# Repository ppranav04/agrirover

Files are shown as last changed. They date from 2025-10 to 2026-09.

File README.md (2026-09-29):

# Agrirover: Tomato Detection and 3D Localization on a Mobile Manipulator

Semester 7 Project-I, B.Tech Mechatronics and Automation, VIT Chennai (report title: *Agribot*)

Agrirover is a mobile manipulator platform for tomato harvesting. It combines a custom-trained YOLOv8
detector running on a Jetson Orin Nano, 3D localization from RealSense D435 depth, a 5-DOF arm driven
through ROS 2 and an Arduino Uno, and a compliant TPU end-effector.

<p align="center">
  
  
</p>

## Demo

Live tomato detection and 3D localization on the Jetson Orin Nano, followed by the end-effector picking
motion.

https://github.com/user-attachments/assets/91c9d1a5-2fdd-4766-8c50-547cba2d2344

## Results

| Metric | Value |
|---|---|
| Detection precision / recall (ripe) | 0.90 / 0.93 |
| Detection precision / recall (unripe) | 0.94 / 0.91 |
| F1 (ripe / unripe) | 0.91 / 0.92 |
| Test set | 784 annotated samples, overall accuracy 0.92 |
| 3D localization error, 0.15–0.50 m | RMSE 2.03 cm, MAE 0.98 cm |
| Goal-pose frame-to-frame jitter | < 1 mm (X, Y), 0.23 mm (Z) [static target: confirm] |
| Inference time, 480x640 | [5.5–9.3 ms, TensorRT: confirm] |
| Pipeline rate | 28 FPS |

Depth error was measured against [ground-truth method: e.g. tape measure at N distances].

## Perception

A ROS 2 node (`agrirover_perception`) that:

- runs a custom-trained YOLOv8n model on RealSense D435 color frames on a Jetson Orin Nano
  (Ubuntu 22.04, JetPack 6.2, ROS 2 Humble)
- classifies tomatoes as ripe or unripe
- reads depth at each detection's bounding-box center and deprojects it to a 3D point with the camera
  intrinsics
- transforms points from the camera frame to the robot base frame with a calibrated 4x4 transform
- publishes goal poses (`tomato/goal_pose`), RViz markers, a detection-status signal and an annotated
  image stream

## Manipulation

- 5-DOF arm with 3D-printed linkages, MG996R servos and a 500 mm reach
- Software chain: camera node, then IK node, then serial node, then Arduino Uno PWM servo control
- Compliant three-claw TPU end-effector; a worm-gear redesign that moves all three claws synchronously was
  designed in SolidWorks

## Robot description

URDF for the arm, camera mount and mobile base, with bringup launch files in `agrirover_bringup`.

## Roadmap

- MoveIt 2 motion planning between perception output and arm control
- Perception-driven pick-and-place
- Multi-frame tracking
- V-SLAM / LiDAR SLAM field navigation

## Repository structure

```
agrirover/                    Core package
agrirover_bringup/            Launch files, system startup
agrirover_description/        URDF and robot description
agrirover_manipulation/       IK node, serial node, end-effector logic
agrirover_perception/         Detection and 3D localization node
yolov8n_tomato.pt             Trained detection model
Datasets and Misc.zip         Training data and supporting files
```

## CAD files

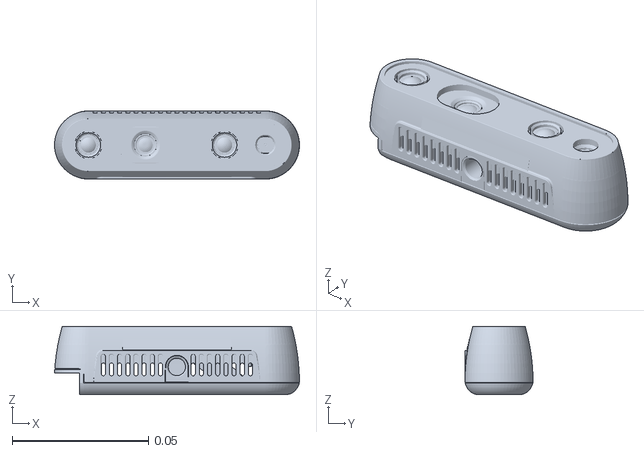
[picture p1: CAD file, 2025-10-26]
agrirover_description/meshes/d435/visual/d435.stl
0.0899 x 0.025 x 0.0251

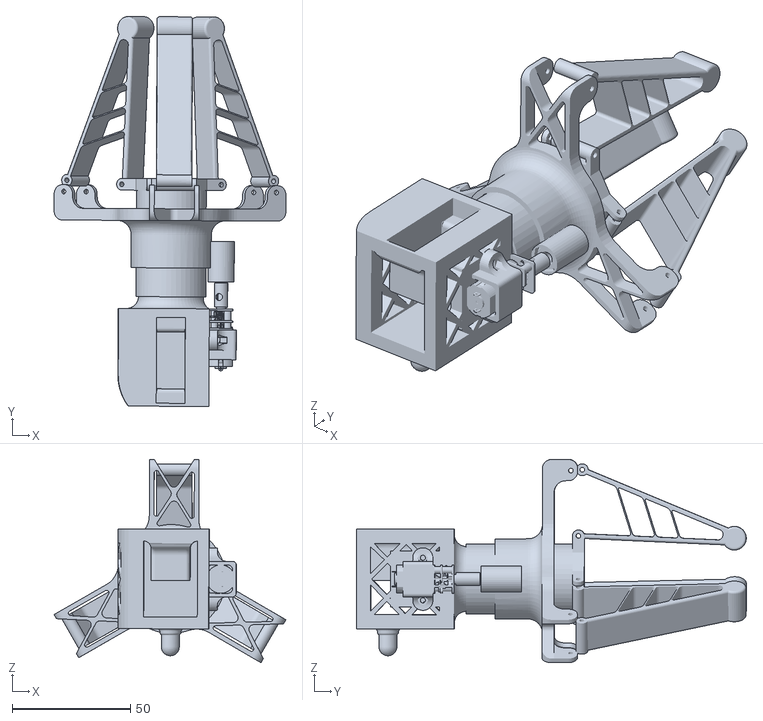
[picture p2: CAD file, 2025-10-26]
agrirover_description/meshes/end_effector.stl
98.1 x 165.0 x 86.0

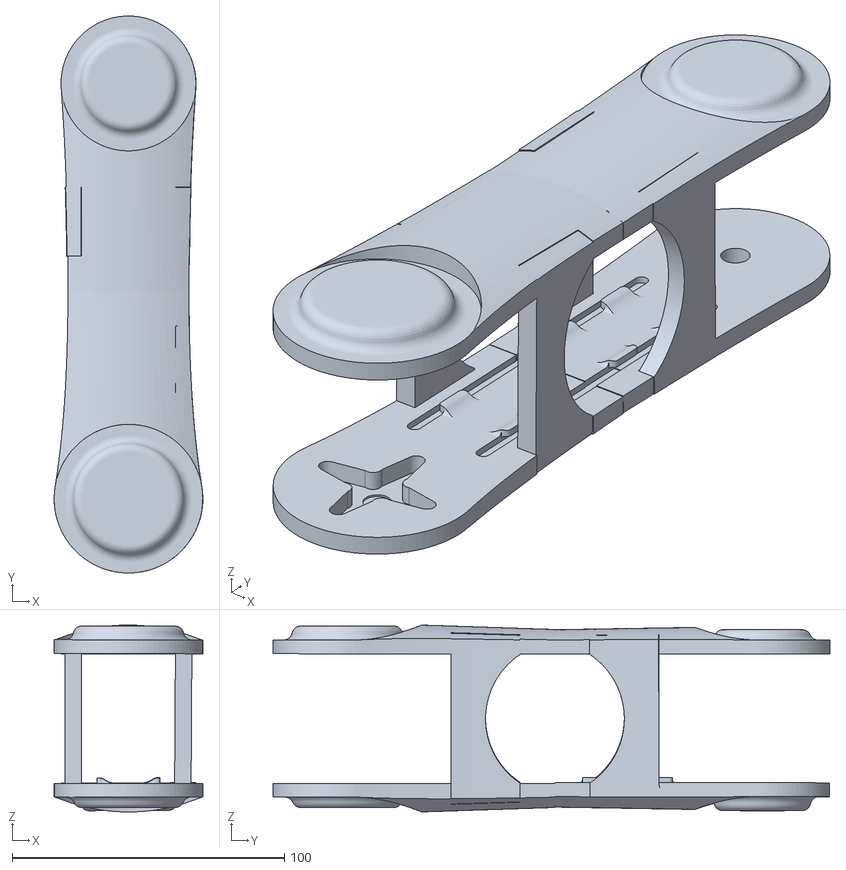
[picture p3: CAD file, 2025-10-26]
agrirover_description/meshes/Link_2.stl
54.7 x 204.6 x 68.7

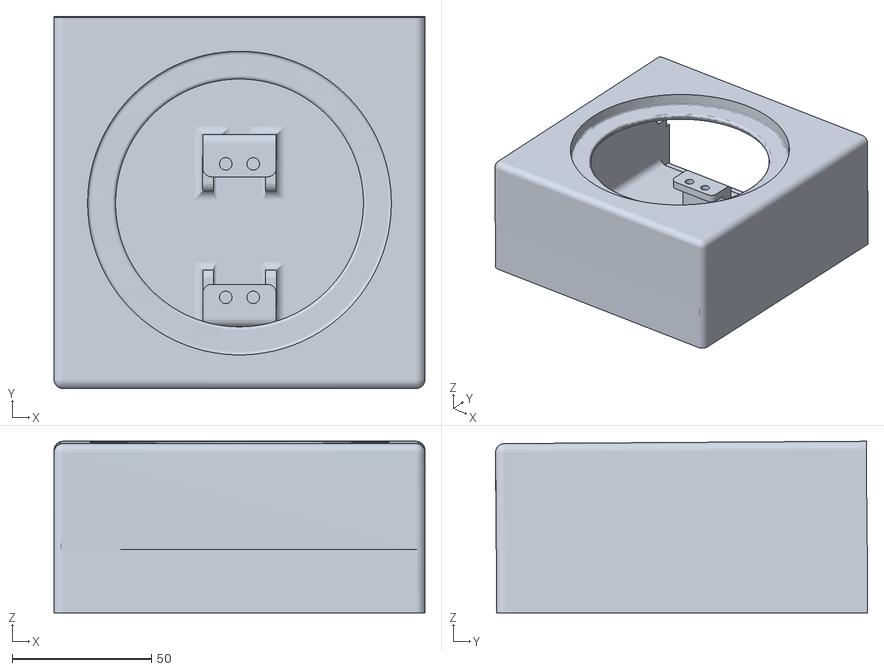
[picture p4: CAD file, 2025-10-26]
agrirover_description/meshes/Base_simplified.stl
133.4 x 133.7 x 61.7

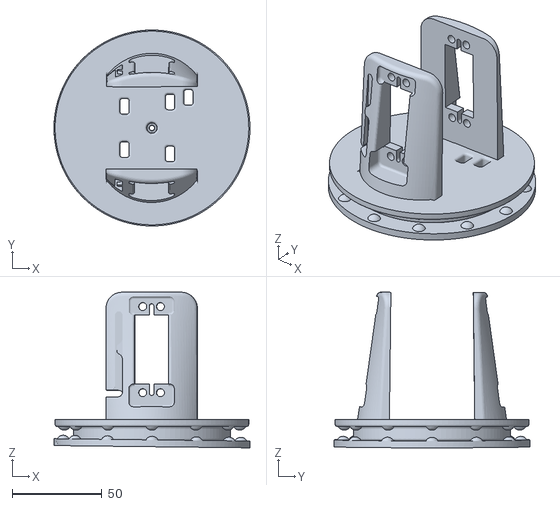
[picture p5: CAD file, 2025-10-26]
agrirover_description/meshes/Link_0_simplified.stl
109.2 x 109.2 x 86.8

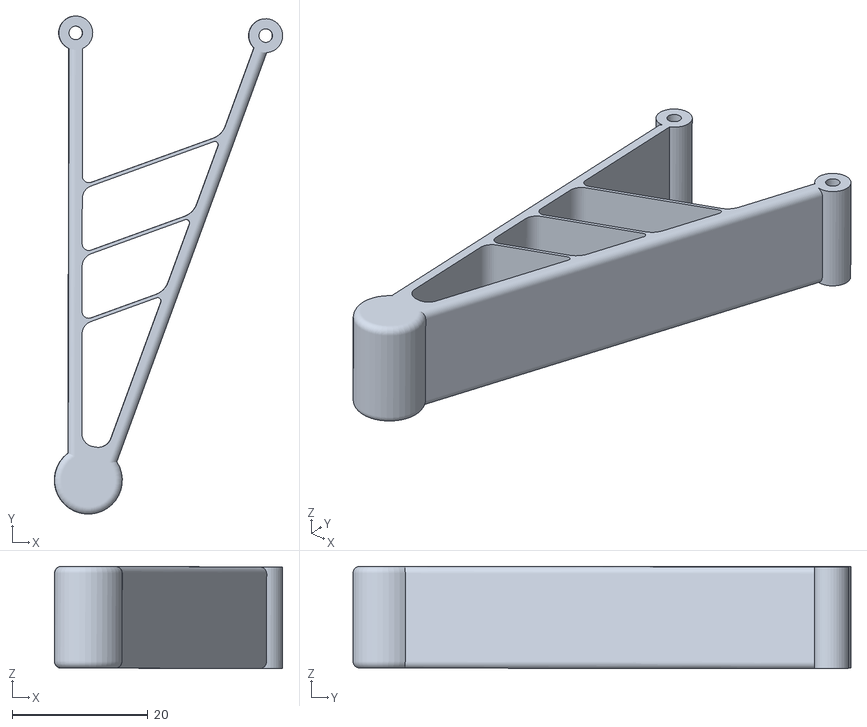
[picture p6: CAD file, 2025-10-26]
agrirover_description/meshes/finger.stl
33.7 x 73.5 x 15.1

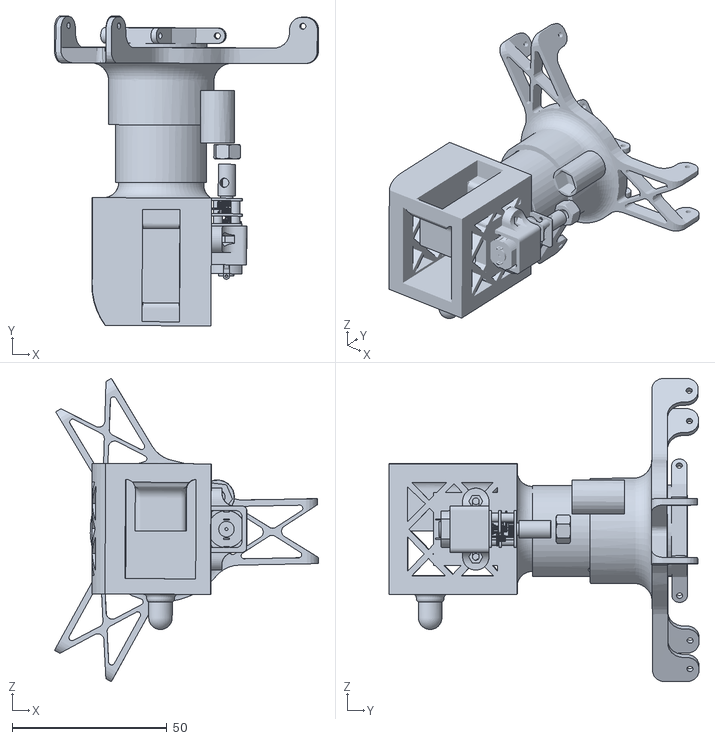
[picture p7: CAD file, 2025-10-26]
agrirover_description/meshes/gripper_simplified.stl
85.4 x 100.2 x 98.1

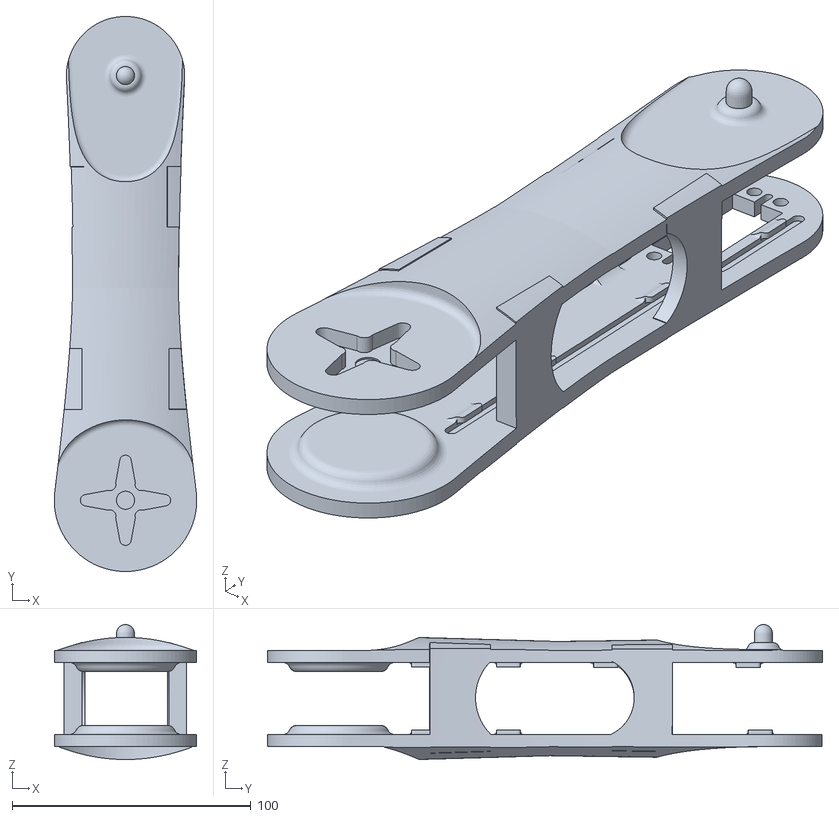
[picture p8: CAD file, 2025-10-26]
agrirover_description/meshes/Link_1.stl
59.7 x 232.5 x 56.6

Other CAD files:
agrirover_description/meshes/Base.stl
agrirover_description/meshes/end_effector_simplified.stl
agrirover_description/meshes/Link_2_simplified.stl
agrirover_description/meshes/gripper.stl
agrirover_description/meshes/Link_0.stl

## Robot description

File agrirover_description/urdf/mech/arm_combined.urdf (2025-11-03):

<?xml version="1.0" ?>
<robot name="agrirover">
  <link name="base_link">
    <inertial>
      <mass value="5.0"/>
      <origin xyz="0 0 0" rpy="0 0 0"/>
      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
    </inertial>
    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
  </link>
  <link name="arm_link_0">
    <inertial>
      <mass value="3.0"/>
      <origin xyz="0 0 0" rpy="0 0 0"/>
      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
    </inertial>
    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
  </link>
  <link name="arm_link_1">
    <inertial>
      <mass value="2.0"/>
      <origin xyz="0 0 0" rpy="0 0 0"/>
      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
    </inertial>
    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
  </link>
  <link name="arm_link_2">
    <inertial>
      <mass value="1.5"/>
      <origin xyz="0 0 0" rpy="0 0 0"/>
      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
    </inertial>
    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
  </link>

  <link name="world">
  </link>
  
  <link name="gripper">
    <inertial>
      <mass value="0.5"/>
      <origin xyz="0 0 0" rpy="0 0 0"/>
      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
    </inertial>
    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
  </link>
  <link name="finger_1">
    <inertial>
      <mass value="0.1"/>
      <origin xyz="0 0 0" rpy="0 0 0"/>
      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
    </inertial>
    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
  </link>
  <link name="finger_2">
    <inertial>
      <mass value="0.1"/>
      <origin xyz="0 0 0" rpy="0 0 0"/>
      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
    </inertial>
    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
  </link>
  <link name="finger_3">
    <inertial>
      <mass value="0.1"/>
      <origin xyz="0 0 0" rpy="0 0 0"/>
      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
    </inertial>
    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
  </link>
  <joint name="world_to_base" type="fixed">
    <parent link="world"/>
    <child link="base_link"/>
    <origin xyz="0 0 0" rpy="0 0 0"/>
  </joint>
  <joint name="base_to_link_0" type="revolute">
    <parent link="base_link"/>
    <child link="arm_link_0"/>
    <origin xyz="0 0 0.03" rpy="0 0 0"/>
    <axis xyz="0 0 1"/>
    <limit effort="10.0" velocity="1.0" lower="0" upper="3.14"/>
  </joint>
  <joint name="link_0_to_link_1" type="revolute">
    <parent link="arm_link_0"/>
    <child link="arm_link_1"/>
    <origin xyz="0 0 0.05" rpy="1.57 1.57 0"/>
    <axis xyz="0 0 1"/>
    <limit effort="10.0" velocity="1.0" lower="0" upper="3.14"/>
  </joint>
  <joint name="link_1_to_link_2" type="revolute">
    <parent link="arm_link_1"/>
    <child link="arm_link_2"/>
    <origin xyz="0 0.176 0" rpy="0 0 -1.57"/>
    <axis xyz="0 0 1"/>
    <limit effort="10.0" velocity="1.0" lower="0" upper="3.14"/>
  </joint>
  <joint name="link_2_to_gripper" type="revolute">
    <parent link="arm_link_2"/>
    <child link="gripper"/>
    <origin xyz="0 0.155 0" rpy="0 0 -1.57"/>
    <axis xyz="0 0 1"/>
    <limit effort="10.0" velocity="1.0" lower="0" upper="3.14"/>
  </joint>
  <joint name="finger_1_joint" type="revolute">
    <parent link="gripper"/>
    <child link="finger_1"/>
    <origin xyz="0.02 0.08 -0.001" rpy="3.14 0 0"/>
    <axis xyz="0 0 1"/>
    <limit effort="10.0" velocity="1.0" lower="0" upper="0.9"/>
  </joint>
  <joint name="finger_2_joint" type="fixed">
    <parent link="gripper"/>
    <child link="finger_2"/>
    <origin xyz="-0.0085 0.08 0.015" rpy="3.14 -2.0944 0"/>
    <axis xyz="0 0 1"/>
  </joint>
  <joint name="finger_3_joint" type="fixed">
    <parent link="gripper"/>
    <child link="finger_3"/>
    <origin xyz="-0.0085 0.08 -0.015" rpy="3.14 2.0944 0"/>
    <axis xyz="0 0 1"/>
  </joint>
  <link name="camera_head_link">
    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
    <inertial>
      <mass value="0.072"/>
      <origin xyz="0 0 0"/>
      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
    </inertial>
  </link>
  <joint name="camera_head_depth_joint" type="fixed">
    <origin xyz="0 0 0" rpy="0 0 0"/>
    <parent link="camera_head_link"/>
    <child link="camera_head_depth_frame"/>
  </joint>
  <link name="camera_head_depth_frame"/>
  <joint name="camera_head_depth_optical_joint" type="fixed">
    <origin xyz="0 0 0" rpy="-1.5707963267948966 0 -1.5707963267948966"/>
    <parent link="camera_head_depth_frame"/>
    <child link="camera_head_depth_optical_frame"/>
  </joint>
  <link name="camera_head_depth_optical_frame"/>
  <joint name="camera_head_infra1_joint" type="fixed">
    <origin xyz="0 0.0 0" rpy="0 0 0"/>
    <parent link="camera_head_link"/>
    <child link="camera_head_infra1_frame"/>
  </joint>
  <link name="camera_head_infra1_frame"/>
  <joint name="camera_head_infra1_optical_joint" type="fixed">
    <origin xyz="0 0 0" rpy="-1.5707963267948966 0 -1.5707963267948966"/>
    <parent link="camera_head_infra1_frame"/>
    <child link="camera_head_infra1_optical_frame"/>
  </joint>
  <link name="camera_head_infra1_optical_frame"/>
  <joint name="camera_head_infra2_joint" type="fixed">
    <origin xyz="0 -0.050 0" rpy="0 0 0"/>
    <parent link="camera_head_link"/>
    <child link="camera_head_infra2_frame"/>
  </joint>
  <link name="camera_head_infra2_frame"/>
  <joint name="camera_head_infra2_optical_joint" type="fixed">
    <origin xyz="0 0 0" rpy="-1.5707963267948966 0 -1.5707963267948966"/>
    <parent link="camera_head_infra2_frame"/>
    <child link="camera_head_infra2_optical_frame"/>
  </joint>
  <link name="camera_head_infra2_optical_frame"/>
  <joint name="camera_head_color_joint" type="fixed">
    <origin xyz="0 0.015 0" rpy="0 0 0"/>
    <parent link="camera_head_link"/>
    <child link="camera_head_color_frame"/>
  </joint>
  <link name="camera_head_color_frame"/>
  <joint name="camera_head_color_optical_joint" type="fixed">
    <origin xyz="0 0 0" rpy="-1.5707963267948966 0 -1.5707963267948966"/>
    <parent link="camera_head_color_frame"/>
    <child link="camera_head_color_optical_frame"/>
  </joint>
  <link name="camera_head_color_optical_frame"/>
  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
  <joint name="gripper_to_camera" type="fixed">
    <parent link="gripper"/>
    <child link="camera_head_link"/>
    <origin xyz="-0.025 0.02 0" rpy="-1.57 0 1.57"/>
  </joint>



</robot>

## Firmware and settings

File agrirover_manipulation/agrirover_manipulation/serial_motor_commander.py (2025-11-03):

#!/usr/bin/env python3
"""
Enhanced Serial Motor Commander (FIXED)
- Pin 5 removed (no hardware)
- 4 servos on pins: 3, 6, 9, 10
- Graceful degradation when hardware unavailable
- Connection retry logic
- Movement queue management
- Better error recovery
"""


import rclpy
from rclpy.node import Node
from std_msgs.msg import Float32MultiArray, Bool
import serial
import math
import time
import numpy as np
from threading import Lock, Thread
from queue import Queue, Empty



class EnhancedSerialMotorCommander(Node):
    def __init__(self):
        super().__init__('serial_motor_commander')
        
        # Declare parameters
        self.declare_parameter('serial_port', '/dev/ttyUSB0')
        self.declare_parameter('baud_rate', 9600)
        self.declare_parameter('interpolation_steps', 20)
        self.declare_parameter('movement_duration', 2.0)
        self.declare_parameter('use_easing', True)
        self.declare_parameter('enable_hardware', False)
        self.declare_parameter('connection_retry_interval', 5.0)
        self.declare_parameter('max_connection_attempts', -1)  # -1 = infinite
        
        # Get parameters
        self.serial_port = self.get_parameter('serial_port').value
        self.baud_rate = self.get_parameter('baud_rate').value
        self.interpolation_steps = self.get_parameter('interpolation_steps').value
        self.movement_duration = self.get_parameter('movement_duration').value
        self.use_easing = self.get_parameter('use_easing').value
        self.enable_hardware = self.get_parameter('enable_hardware').value
        self.retry_interval = self.get_parameter('connection_retry_interval').value
        self.max_attempts = self.get_parameter('max_connection_attempts').value
        
        # Serial connection
        self.ser = None
        self.connection_lock = Lock()
        self.is_connected = False
        self.connection_attempts = 0
        
        # Movement tracking
        self.current_positions = None
        self.movement_lock = Lock()
        self.movement_queue = Queue(maxsize=5)
        self.is_moving = False
        
        # Publishers
        self.connection_status_pub = self.create_publisher(
            Bool, 'serial/connection_status', 10
        )
        
        # Subscribers
        self.servo_sub = self.create_subscription(
            Float32MultiArray,
            'servo_angles',
            self.servo_callback,
            10
        )
        
        # Initialize connection
        if self.enable_hardware:
            self.connect_to_serial()
            
            # Retry timer if connection fails
            if not self.is_connected:
                self.retry_timer = self.create_timer(
                    self.retry_interval,
                    self.retry_connection
                )
        else:
            self.get_logger().info('Hardware disabled - running in simulation mode')
        
        # Start movement worker thread
        self.movement_thread = Thread(target=self.movement_worker, daemon=True)
        self.movement_thread.start()
        
        self.get_logger().info('═══════════════════════════════════════')
        self.get_logger().info('  Enhanced Serial Motor Commander')
        self.get_logger().info('═══════════════════════════════════════')
        self.get_logger().info(f'Serial port: {self.serial_port}')
        self.get_logger().info(f'Baud rate: {self.baud_rate}')
        self.get_logger().info(f'Hardware enabled: {self.enable_hardware}')
        self.get_logger().info(f'Servos: 4 (pins: 3, 6, 9, 10)')
        self.get_logger().info(f'Interpolation: {self.interpolation_steps} steps')
        self.get_logger().info(f'Duration: {self.movement_duration}s')
    
    def connect_to_serial(self):
        """Attempt to connect to serial port"""
        try:
            with self.connection_lock:
                if self.ser is not None:
                    self.ser.close()
                
                self.ser = serial.Serial(
                    self.serial_port,
                    self.baud_rate,
                    timeout=1
                )
                self.is_connected = True
                self.connection_attempts = 0
                
                self.get_logger().info(
                    f'✓ Connected to {self.serial_port} at {self.baud_rate} baud'
                )
                
                # Publish connection status
                status_msg = Bool()
                status_msg.data = True
                self.connection_status_pub.publish(status_msg)
                
                return True
                
        except serial.SerialException as e:
            self.is_connected = False
            self.get_logger().error(f'✗ Failed to connect: {e}')
            
            # Publish connection status
            status_msg = Bool()
            status_msg.data = False
            self.connection_status_pub.publish(status_msg)
            
            return False
    
    def retry_connection(self):
        """Retry serial connection periodically"""
        if self.is_connected:
            self.retry_timer.cancel()
            return
        
        self.connection_attempts += 1
        
        if self.max_attempts > 0 and self.connection_attempts > self.max_attempts:
            self.get_logger().error(
                f'✗ Max connection attempts ({self.max_attempts}) reached'
            )
            self.retry_timer.cancel()
            return
        
        self.get_logger().info(
            f'Retrying connection (attempt {self.connection_attempts})...'
        )
        
        if self.connect_to_serial():
            self.retry_timer.cancel()
    
    def ease_in_out_cubic(self, t):
        """Cubic ease-in-out easing function"""
        if t < 0.5:
            return 4 * t * t * t
        else:
            return 1 - pow(-2 * t + 2, 3) / 2
    
    def interpolate_trajectory(self, start_positions, target_positions):
        """Generate smooth interpolated trajectory"""
        trajectory = []
        
        for i in range(self.interpolation_steps + 1):
            t = i / self.interpolation_steps
            
            if self.use_easing:
                t_eased = self.ease_in_out_cubic(t)
            else:
                t_eased = t
            
            interpolated_position = []
            for start, target in zip(start_positions, target_positions):
                pos = start + (target - start) * t_eased
                interpolated_position.append(pos)
            
            trajectory.append(interpolated_position)
        
        return trajectory
    
    def servo_callback(self, msg: Float32MultiArray):
        """Handle incoming servo angle commands"""
        target_positions = list(msg.data)
        
        # Validate: should have 4 servo angles
        if len(target_positions) != 4:
            self.get_logger().error(
                f'Expected 4 servo angles, got {len(target_positions)}'
            )
            return
        
        # Initialize current positions on first command
        if self.current_positions is None:
            self.current_positions = target_positions
            self.get_logger().info('Initialized current positions')
        
        # Add to movement queue
        try:
            self.movement_queue.put_nowait(target_positions)
            self.get_logger().debug(f'Added movement to queue (size: {self.movement_queue.qsize()})')
        except:
            self.get_logger().warn('Movement queue full, dropping command')
    
    def movement_worker(self):
        """Worker thread for executing movements"""
        while rclpy.ok():
            try:
                # Get next movement from queue (blocking)
                target_positions = self.movement_queue.get(timeout=0.1)
                
                with self.movement_lock:
                    self.is_moving = True
                    self.execute_movement(target_positions)
                    self.is_moving = False
                
                self.movement_queue.task_done()
                
            except Empty:
                continue
            except Exception as e:
                self.get_logger().error(f'Movement worker error: {e}')
    
    def execute_movement(self, target_positions):
        """Execute smooth movement to target positions"""
        if not self.enable_hardware:
            # Simulation mode
            self.get_logger().info(
                f'[SIM] Moving to: {[f"{p:.2f}" for p in target_positions]}'
            )
            time.sleep(self.movement_duration)
            self.current_positions = target_positions
            return
        
        if not self.is_connected or self.ser is None:
            self.get_logger().error('Serial port not connected')
            return
        
        try:
            # Generate trajectory
            trajectory = self.interpolate_trajectory(
                self.current_positions, target_positions
            )
            
            step_delay = self.movement_duration / self.interpolation_steps
            
            self.get_logger().info(
                f'Executing movement: {len(trajectory)} steps over {self.movement_duration}s'
            )
            
            # Send each position
            for i, position_rad in enumerate(trajectory):
                # Convert to degrees
                angles_deg = [
                    max(0, min(180, int(math.degrees(angle))))
                    for angle in position_rad
                ]
                
                # Send command - 4 servos
                command_str = ','.join(map(str, angles_deg)) + '\n'
                
                with self.connection_lock:
                    if self.ser is not None:
                        self.ser.write(command_str.encode('utf-8'))
                
                # Log progress
                if i % 5 == 0 or i == len(trajectory) - 1:
                    self.get_logger().debug(
                        f'Step {i}/{len(trajectory)}: {angles_deg}'
                    )
                
                # Wait
                if i < len(trajectory) - 1:
                    time.sleep(step_delay)
            
            # Update current position
            self.current_positions = target_positions
            self.get_logger().info('✓ Movement complete')
            
        except serial.SerialException as e:
            self.get_logger().error(f'Serial error during movement: {e}')
            self.is_connected = False
            
            # Try to reconnect
            if self.enable_hardware:
                self.connect_to_serial()
        
        except Exception as e:
            self.get_logger().error(f'Movement execution error: {e}')
    
    def destroy_node(self):
        """Cleanup on shutdown"""
        if self.ser is not None:
            try:
                self.ser.close()
                self.get_logger().info('Serial port closed')
            except:
                pass
        
        super().destroy_node()



def main(args=None):
    rclpy.init(args=args)
    
    try:
        node = EnhancedSerialMotorCommander()
        rclpy.spin(node)
    except KeyboardInterrupt:
        pass
    finally:
        if rclpy.ok():
            rclpy.shutdown()



if __name__ == '__main__':
    main()

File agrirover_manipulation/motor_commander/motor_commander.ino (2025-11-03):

#include <Servo.h>

Servo servos[5];                // Array for 5 servos
const int servoPins[4] = {3, 6, 9, 10}; // PWM pins where servos are connected

const byte numServos = 5;
const byte maxLength = 64;
char inputString[maxLength];    // Buffer for incoming serial data
byte inputPos = 0;

void setup() {
  Serial.begin(9600);
  for (byte i = 0; i < numServos; i++) {
    servos[i].attach(servoPins[i]);
  }
  Serial.println("Ready to receive servo angles");
}

void loop() { 
  while (Serial.available() > 0) {
    char inChar = Serial.read();

    if (inChar == '\n') {  // End of command
      inputString[inputPos] = '\0';  // Null-terminate string
      processCommand(inputString);
      inputPos = 0;  // Reset buffer position
    } 
    else if (inputPos < maxLength - 1) {
      inputString[inputPos++] = inChar;
    }
  }
}

void processCommand(char* command) {
  int values[numServos];
  byte index = 0; 

  char* token = strtok(command, ",");
  while (token != NULL && index < numServos) {
    values[index++] = atoi(token);  // Convert string to int
    token = strtok(NULL, ",");
  }

  if (index == numServos) {
    // Move servos and print complementary angles
    Serial.print("Servo angles: ");
    for (byte i = 0; i < numServos; i++) {
      int angle = constrain(values[i], 0, 180);
      servos[i].write(angle);
      Serial.print(angle);
      if (i < numServos - 1) Serial.print(", ");
    }
    Serial.println();
  } else {
    Serial.println("Error: Invalid number of angles received");
  }
}

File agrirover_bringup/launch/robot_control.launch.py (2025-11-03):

"""
Improved Launch File for Agricultural Robot Arm Manipulation (FIXED)
- Pin 5 removed: 4 servos on pins 3, 6, 9, 10
- Updated home position: 4 angles instead of 5
- Camera attached to gripper (dynamic transform from URDF)
- Manual goal pose input with xterm visualization
- RViz marker visualization
- Improved node sequencing and error handling
- Configurable parameters
"""


from launch import LaunchDescription
from launch_ros.actions import Node
from launch.actions import (
    DeclareLaunchArgument, 
    TimerAction, 
    LogInfo,
)
from launch.substitutions import (
    LaunchConfiguration, 
    PathJoinSubstitution,
)
from launch_ros.substitutions import FindPackageShare
from ament_index_python.packages import get_package_share_directory
import os
import launch



def generate_launch_description():
    """
    Launch configuration for agricultural robot arm with manual goal pose input.
    
    Key improvements:
    - Removed pin 5 servo (no hardware)
    - 4 servos on pins: 3, 6, 9, 10
    - Updated home position to 4 angles
    - Removed static TF publisher (camera is attached to gripper via URDF)
    - Better parameter organization
    - Improved logging and startup messaging
    - Conditional node launching
    - Workspace bounds aligned with actual robot reach
    """
    
    # ============================================================
    # DECLARE LAUNCH ARGUMENTS
    # ============================================================
    
    # Hardware Configuration
    serial_port_arg = DeclareLaunchArgument(
        'serial_port',
        default_value='/dev/ttyUSB0',
        description='Serial port for motor controller (e.g., /dev/ttyUSB0 or /dev/ttyACM0)'
    )
    
    baud_rate_arg = DeclareLaunchArgument(
        'baud_rate',
        default_value='9600',
        description='Serial communication baud rate'
    )
    
    use_hardware_arg = DeclareLaunchArgument(
        'use_hardware',
        default_value='false',
        description='Enable actual hardware control (motor serial communication)'
    )
    
    # Visualization Configuration
    use_rviz_arg = DeclareLaunchArgument(
        'use_rviz',
        default_value='true',
        description='Launch RViz2 for visualization'
    )
    
    rviz_config_arg = DeclareLaunchArgument(
        'rviz_config',
        default_value=PathJoinSubstitution([
            FindPackageShare('agrirover_manipulation'),
            'rviz',
            'agrirover_visualization.rviz'
        ]),
        description='Path to RViz configuration file'
    )
    
    # Robot Configuration
    urdf_file_arg = DeclareLaunchArgument(
        'urdf_file',
        default_value=PathJoinSubstitution([
            FindPackageShare('agrirover_description'),
            'urdf',
            'mech',
            'arm_combined.urdf'
        ]),
        description='Path to robot URDF file'
    )
    
    # FIXED: 4 angles instead of 5
    home_position_arg = DeclareLaunchArgument(
        'home_position',
        default_value='[1.57, 0.0, 3.14, 3.14]',
        description='Home position joint angles in radians [joint1, joint2, joint3, joint4] - 4 servos'
    )
    
    # Movement Parameters
    interpolation_steps_arg = DeclareLaunchArgument(
        'interpolation_steps',
        default_value='20',
        description='Number of interpolation steps for smooth trajectory'
    )
    
    movement_duration_arg = DeclareLaunchArgument(
        'movement_duration',
        default_value='2.0',
        description='Duration of smooth movement in seconds'
    )
    
    use_easing_arg = DeclareLaunchArgument(
        'use_easing',
        default_value='true',
        description='Enable cubic ease-in-out function for smooth motion'
    )
    
    # Frame Configuration
    base_frame_arg = DeclareLaunchArgument(
        'base_frame',
        default_value='base_link',
        description='Robot base frame (fixed reference)'
    )
    
    camera_frame_arg = DeclareLaunchArgument(
        'camera_frame',
        default_value='camera_head_link',
        description='Camera frame (attached to gripper)'
    )
    
    # Manual Input Configuration
    input_frame_arg = DeclareLaunchArgument(
        'input_frame',
        default_value='base_link',
        description='Reference frame for manual goal pose input (base_link or camera_head_link)'
    )
    
    # IK Solver Configuration
    workspace_x_min_arg = DeclareLaunchArgument(
        'workspace_x_min',
        default_value='-0.5',
        description='Minimum X reach of workspace (meters)'
    )
    
    workspace_x_max_arg = DeclareLaunchArgument(
        'workspace_x_max',
        default_value='0.5',
        description='Maximum X reach of workspace (meters)'
    )
    
    workspace_y_min_arg = DeclareLaunchArgument(
        'workspace_y_min',
        default_value='-0.5',
        description='Minimum Y reach of workspace (meters)'
    )
    
    workspace_y_max_arg = DeclareLaunchArgument(
        'workspace_y_max',
        default_value='0.5',
        description='Maximum Y reach of workspace (meters)'
    )
    
    workspace_z_min_arg = DeclareLaunchArgument(
        'workspace_z_min',
        default_value='0.0',
        description='Minimum Z reach of workspace (meters)'
    )
    
    workspace_z_max_arg = DeclareLaunchArgument(
        'workspace_z_max',
        default_value='0.8',
        description='Maximum Z reach of workspace (meters)'
    )
    
    # ============================================================
    # LOAD ROBOT DESCRIPTION FROM URDF
    # ============================================================
    
    try:
        robot_urdf_path = os.path.join(
            get_package_share_directory('agrirover_description'),
            'urdf', 'mech', 'arm_combined.urdf'
        )
        with open(robot_urdf_path, 'r') as f:
            robot_description_xml = f.read()
    except Exception as e:
        print(f"✗ Error loading URDF: {e}")
        robot_description_xml = ""
    
    # ============================================================
    # NODE DEFINITIONS
    # ============================================================
    
    # 1. Custom Robot State Publisher
    # Publishes joint states from servo commands
    # FIXED: Updated for 4 servos
    robot_state_publisher_node = Node(
        package='agrirover_manipulation',
        executable='robot_state_publisher_node',
        name='robot_state_publisher_node',
        output='screen',
        parameters=[{
            'home_position': LaunchConfiguration('home_position'),
            'publish_rate': 50.0,
        }],
        emulate_tty=True,
        respawn=False,
        respawn_delay=2.0,
    )
    
    # 2. Built-in Robot State Publisher
    # Publishes TF transforms from joint states (uses URDF)
    builtin_robot_state_publisher = Node(
        package='robot_state_publisher',
        executable='robot_state_publisher',
        name='robot_state_publisher',
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

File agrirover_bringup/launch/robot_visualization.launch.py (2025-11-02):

from launch import LaunchDescription
from launch_ros.actions import Node
from launch.actions import (
    DeclareLaunchArgument, 
    TimerAction, 
    LogInfo,
)
from launch.substitutions import (
    LaunchConfiguration, 
    PathJoinSubstitution,
)
from launch_ros.substitutions import FindPackageShare
from ament_index_python.packages import get_package_share_directory
import os
import launch


def generate_launch_description():
    """
    Enhanced launch file with:
    - Proper startup sequencing
    - Configurable parameters via launch arguments
    - Better error handling
    - Conditional node launching
    - Camera-based goal pose publishing (no manual input)
    """
    
    # ============================================================
    # DECLARE LAUNCH ARGUMENTS
    # ============================================================
    
    # Hardware arguments
    serial_port_arg = DeclareLaunchArgument(
        'serial_port',
        default_value='/dev/ttyUSB0',
        description='Serial port for motor controller'
    )
    
    baud_rate_arg = DeclareLaunchArgument(
        'baud_rate',
        default_value='9600',
        description='Baud rate for serial communication'
    )
    
    use_hardware_arg = DeclareLaunchArgument(
        'use_hardware',
        default_value='false',
        description='Enable hardware (serial) communication'
    )
    
    # Visualization arguments
    use_rviz_arg = DeclareLaunchArgument(
        'use_rviz',
        default_value='true',
        description='Launch RViz for visualization'
    )
    
    rviz_config_arg = DeclareLaunchArgument(
        'rviz_config',
        default_value=PathJoinSubstitution([
            FindPackageShare('agrirover_manipulation'),
            'rviz',
            'agrirover_visualization.rviz'
        ]),
        description='Path to RViz configuration file'
    )
    
    # Robot description arguments
    urdf_file_arg = DeclareLaunchArgument(
        'urdf_file',
        default_value=PathJoinSubstitution([
            FindPackageShare('agrirover_description'),
            'urdf',
            'mech',
            'arm_combined.urdf'
        ]),
        description='Path to robot URDF file'
    )
    
    # IK solver arguments
    home_position_arg = DeclareLaunchArgument(
        'home_position',
        default_value='[1.57, 1.57, 0.9, 0.8, 0.0]',
        description='Home position joint angles in radians'
    )
    
    # Movement parameters
    interpolation_steps_arg = DeclareLaunchArgument(
        'interpolation_steps',
        default_value='20',
        description='Number of interpolation steps for smooth movement'
    )
    
    movement_duration_arg = DeclareLaunchArgument(
        'movement_duration',
        default_value='2.0',
        description='Duration of movement in seconds'
    )
    
    use_easing_arg = DeclareLaunchArgument(
        'use_easing',
        default_value='true',
        description='Use easing function for smoother motion'
    )
    
    # Frame IDs
    base_frame_arg = DeclareLaunchArgument(
        'base_frame',
        default_value='base_link',
        description='Base frame of the robot'
    )
    
    camera_frame_arg = DeclareLaunchArgument(
        'camera_frame',
        default_value='camera_head_link',
        description='Camera frame ID'
    )
    
    # Camera arguments
    camera_type_arg = DeclareLaunchArgument(
        'camera_type',
        default_value='webcam',
        description='Camera type: webcam or realsense'
    )
    
    camera_id_arg = DeclareLaunchArgument(
        'camera_id',
        default_value='0',
        description='Camera device ID (for webcam)'
    )
    
    z_distance_arg = DeclareLaunchArgument(
        'z_distance',
        default_value='0.5',
        description='Depth distance for webcam (in meters)'
    )
    
    model_path_arg = DeclareLaunchArgument(
        'model_path',
        default_value='/home/pranav/agrirover_ws/src/yolov8n_tomato.pt',
        description='Path to YOLO model file'
    )
    
    detection_timeout_arg = DeclareLaunchArgument(
        'detection_timeout',
        default_value='3.0',
        description='Timeout for detection before moving home (seconds)'
    )
    
    # ============================================================
    # LOAD ROBOT DESCRIPTION
    # ============================================================
    
    try:
        robot_urdf_path = os.path.join(
            get_package_share_directory('agrirover_description'),
            'urdf', 'mech', 'arm_combined.urdf'
        )
        with open(robot_urdf_path, 'r') as f:
            robot_description_xml = f.read()
    except Exception as e:
        print(f"Error loading URDF: {e}")
        robot_description_xml = ""
    
    # ============================================================
    # NODE DEFINITIONS
    # ============================================================
    
    # 1. Robot State Publisher (custom) - Publishes joint states
    robot_state_publisher_node = Node(
        package='agrirover_manipulation',
        executable='robot_state_publisher_node',
        name='robot_state_publisher_node',
        output='screen',
        parameters=[{
            'home_position': LaunchConfiguration('home_position'),
        }],
        emulate_tty=True,
        respawn=False,
        respawn_delay=2.0,
    )
    
    # 2. Robot State Publisher (built-in) - Publishes TF transforms
    builtin_robot_state_publisher = Node(
        package='robot_state_publisher',
        executable='robot_state_publisher',
        name='robot_state_publisher',
        output='screen',
        parameters=[{
            'robot_description': robot_description_xml,
            'publish_frequency': 50.0,  # Hz
        }],
        emulate_tty=True,
    )
    
    # 4. IK Solver Node - Delayed start to wait for transforms
    ik_solver_node = TimerAction(
        period=2.0,  # Wait 2 seconds for TF tree to be ready
        actions=[
            Node(
                package='agrirover_manipulation',
                executable='ik_solver',
                name='ik_solver_node',
                output='screen',
                parameters=[{
                    'home_position': LaunchConfiguration('home_position'),
                    'tf_timeout': 2.0,
                    'ik_timeout': 1.0,
                    'max_ik_iterations': 100,
                    'position_tolerance': 0.01,
                    'num_ik_solutions': 5,
                    'manipulability_threshold': 0.01,
                    'base_frame': LaunchConfiguration('base_frame'),
                    'camera_frame': LaunchConfiguration('camera_frame'),
                }],
                emulate_tty=True,
                respawn=True,
                respawn_delay=3.0,
            )
        ]
    )
    
    # 5. Serial Motor Commander Node
    serial_motor_commander = Node(
        package='agrirover_manipulation',
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

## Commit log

2025-10-26 feat: First principles restructuring
    [Base.stl, Base_simplified.stl, Link_0.stl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]
2025-11-02 (feat): home position and basic code configuration
    [arm.urdf.xacro, arm_combined.urdf, intel_rgbd_cam_d435.urdf.xacro]
2025-11-03 (feat): URDF Corrected
    [arm_combined.urdf]
2025-11-03 (feat): URDF re-corected
    [arm_combined.urdf]
